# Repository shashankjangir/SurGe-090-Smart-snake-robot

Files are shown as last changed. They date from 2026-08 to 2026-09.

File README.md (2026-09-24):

<p align="center">
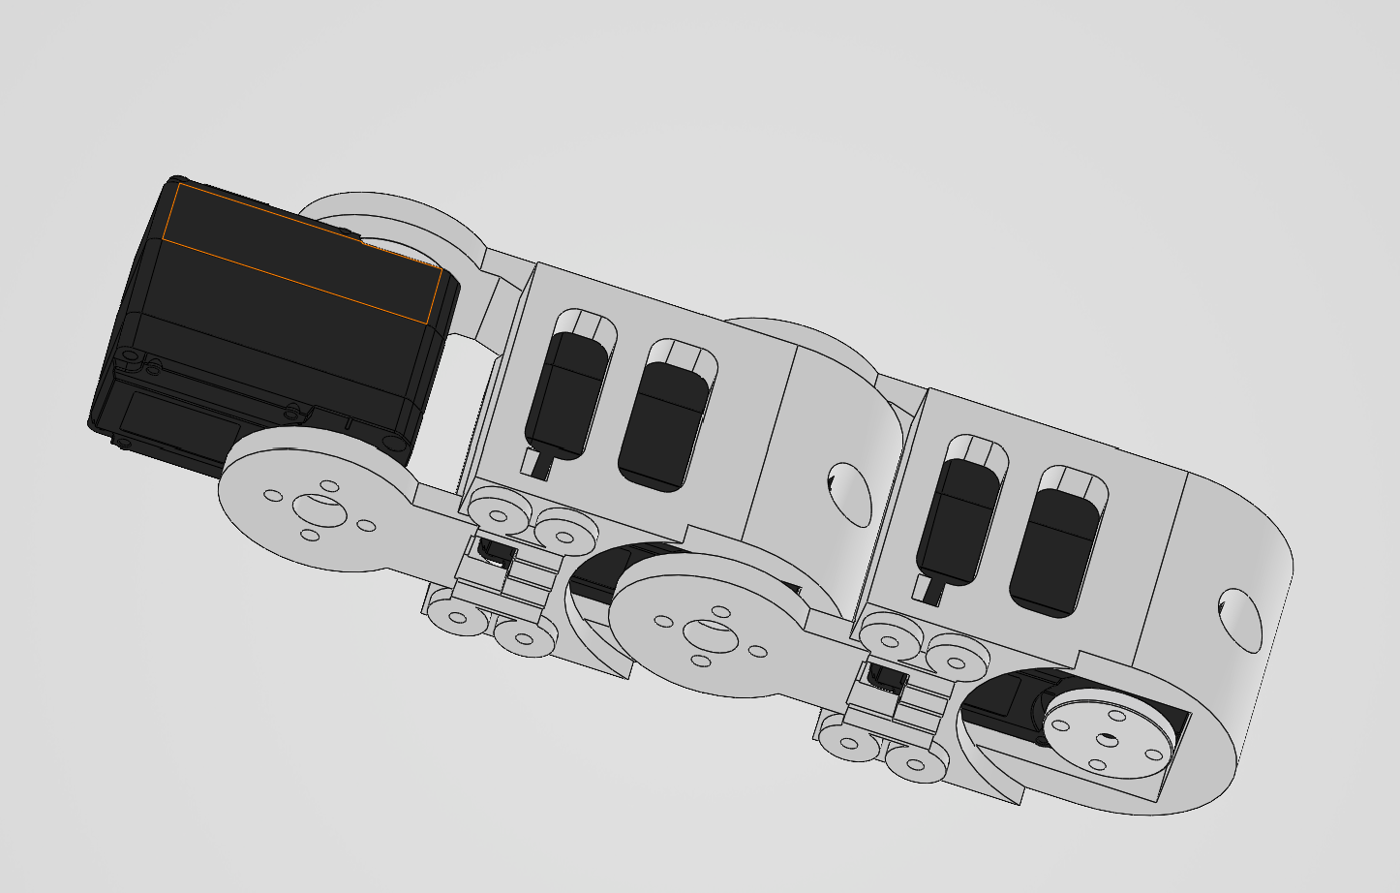
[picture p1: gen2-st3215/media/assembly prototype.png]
SURGE-090 gen2 assembly prototype
  
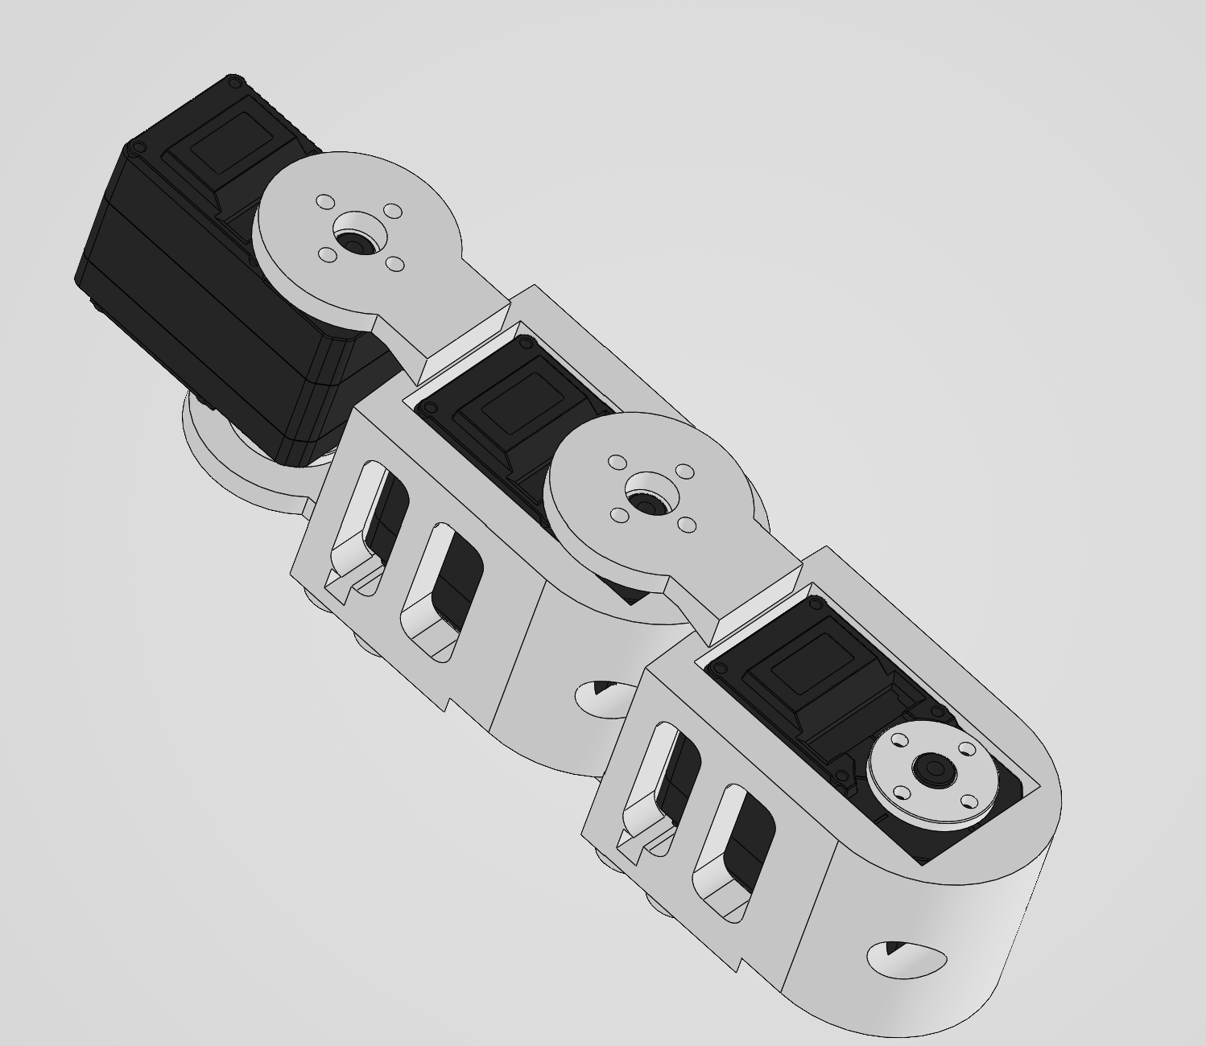
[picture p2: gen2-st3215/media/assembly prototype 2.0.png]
SURGE-090 gen2 assembly prototype 2.0
  
</p>

<h1 align="center">SURGE-090 · Smart Snake Robot 🐍</h1>

<p align="center">
  <b>SURGE Summer Research Programme · Indian Institute of Technology Delhi · 2026</b>
</p>

<p align="center">
  <a href="#abstract">Abstract</a> •
  <a href="#project-status">Status</a> •
  <a href="#the-two-generations">Generations</a> •
  <a href="#system-architecture">Architecture</a> •
  <a href="#repository-structure">Structure</a> •
  <a href="#quick-start">Quick Start</a> •
  <a href="#team">Team</a>
</p>

---

> **Updated 24 Sep 2026.** What we did before and what we do now is recorded in [What changed](#what-changed) at the end of this file.

## Abstract

**SURGE-090** is a ten-degree-of-freedom, bio-inspired snake robot intended for locomotion in unstructured and confined environments. It propels itself by **sinusoidal lateral undulation**, and its central research contribution is **sensorless collision detection**: motor current is monitored continuously, and a stall-current spike is used as a tactile obstacle signal, removing the need for any external proximity or force sensor.

The project was carried out under the **SURGE (Summer Undergraduate Research Grant for Excellence)** programme at **IIT Delhi** in summer 2026, on a ₹1,00,000 grant. It passed through two hardware generations, and the transition between them is the central event in the project's history — see [Why there are two generations](#why-there-are-two-generations).

> **This README is a research log, not a product page.** Every subsystem below is tagged with its real state. Where something is designed but not built, it says so.

---

## Project Status

**Overall: design, simulation, Python bench stack, ESP32 firmware, web dashboard, and desktop app complete; integrated hardware build pending.**

| Subsystem | State | Notes |
|---|---|---|
| Serpenoid gait generator (Python) | 🟢 **Implemented** | Sound math; verified on bench & simulation |
| Current-threshold collision detection | 🟢 **Implemented** | 350 mA (Gen 1) / 1200 mA default (Gen 2); requires bench calibration |
| Evasion state machine | 🟢 **Implemented** | SLITHER → REV (2.5 s) → TURN (4.0 s) → SLITHER |
| Side-aware turn direction | 🟡 **Implemented** | Uses current sign (torque direction); phase-correlation recommended |
| Dynamixel XL330 bus driver (Gen 1) | 🟡 **Written, bench tested** | Verified against **2** motors; 10-motor path written |
| ST3215 servo driver & protocol (Gen 2) | 🟢 **Implemented** | Feetech SCS half-duplex bus @ 1 Mbps with mock support (`gen2-st3215/src/`) |
| ESP32 robot firmware (Gen 2) | 🟢 **Implemented** | Field firmware of record `robot_esp32_v2.cpp`: CPG gait, MPU6050, ESP-NOW, limp boot, per-group soft start, ±70° limits, low-battery/over-temp stop (`robot_esp32` superseded) |
| ESP32 receiver + transmitter | 🟢 **Implemented** | OLED + NeoPixel receiver, ESP-NOW transmitter (`gen2-st3215/firmware/`) |
| ESP-NOW telemetry link (Gen 2) | 🟢 **Implemented** | Broadcast link from robot to base station (`base_esp32.ino` + `base_station.py`) |
| PyBullet physics simulation | 🟢 **Implemented** | 10-segment URDF digital twin with GUI + headless modes (`shared/simulation/pybullet/`) |
| Pure pursuit path following | 🟢 **Implemented** | Kinematic prediction + pure pursuit steering (`gen2-st3215/src/path_engine.py`) |
| Web dashboard (Flask) | 🟢 **Implemented** | REST API, 2D canvas, 3D Three.js viewer, telemetry (`shared/web-dashboard/`) |
| Desktop control app (Tkinter) | 🟢 **Implemented** | GUI + headless mode, path drawing, accuracy reports (`shared/desktop-app/`) |
| ESP32 gait simulation (Wokwi) | 🟢 **Working** | 5 PWM servos, HC-SR04, MPU6050, OLED, interactive serial console |
| Body segment CAD — v1/v2 (SolidWorks) | 🟢 **Printed** | 2 segments printed and measured (Gen 1 Dynamixel) |
| Body segment CAD — v4 (CadQuery) | 🟢 **Complete** | Gen 2 baseline design |
| Body segment CAD — v5 (CadQuery) | 🟡 **Superseded** | Addressed sidewalls; superseded by v6 |
| Body segment CAD — v6 (CadQuery) | 🟢 **Complete (Design of record)** | Fixes ground clearance, scale orientation & retention (`gen2-st3215/cad/segments/v6/`) |
| v2.0 electrical architecture | 🟢 **Specified** | Split power bus v3: 15 A main fuse → loop key → 5 groups of 2 servos, 3 A fuse per group ([`docs/hardware/power_split_bus_v3.md`](docs/hardware/power_split_bus_v3.md)) |
| Assembled 10-DOF physical robot | 🔴 **Pending** | Full 10-motor physical chain assembly pending actuator procurement |

### The hardware blocker

**Only 2 of the 10 planned Dynamixel XL330-M288-T motors were obtained for Gen 1**, after which the part became unavailable in the Indian market. The project was subsequently transitioned to **Waveshare ST3215** serial bus servos, which are readily sourced in India and deliver 2.94 N·m torque (~5.7× the XL330).

### Anisotropic friction requirement

`snake_locomotion.py` generates a planar undulation that produces forward thrust **only if the belly has anisotropic friction** — low resistance sliding forward, high resistance sliding sideways/backward.

The **v6 CAD** addresses this with longitudinal keel features and directional ground contact geometry. Printing and evaluating a single v6 test segment on the target surface is recommended to measure forward/backward traction before full assembly.

---

## Why there are two generations

The redesign was **forced by component supply, not chosen on engineering grounds.** The commit that opens generation 2 records it plainly:

```
a32b675  2026-08-20  "No dynamixel in the market. So switched to Servos"
```

After a six-week stall waiting on motors that were not going to arrive, the architecture was rebuilt around **Waveshare ST3215** serial bus servos, which are readily sourced in India and carry substantially more torque. The move brought genuine secondary benefits — roughly 5.7× the joint torque, and a 12 V rail that supports a larger robot — but those are consequences of the switch, not the reason for it.

---

## The Two Generations

### `gen1-dynamixel/` — original design

| Aspect | Detail |
|---|---|
| **Motors** | 10× ROBOTIS Dynamixel XL330-M288-T (0.52 N·m, 1.5 A stall @ 5 V) — **2 obtained** |
| **Interface** | ROBOTIS U2D2 + Power Hub Board, TTL daisy chain, Protocol 2.0 |
| **Compute** | Raspberry Pi (4 in BOM, 5 used in lab), Python + `dynamixel-sdk` |
| **Power** | 5 V / 10 A SMPS, tethered |
| **Encoder** | 12-bit magnetic absolute, 0.088°/step |
| **Status** | Control stack written; verified on 2-motor bench |
| **Documentation** | [`gen1-dynamixel/README.md`](gen1-dynamixel/README.md) |

### `gen2-st3215/` — ST3215 + ESP32 redesign

| Aspect | Detail |
|---|---|
| **Motors** | 10× Waveshare ST3215 (2.94 N·m / 30 kg·cm, 2.7 A stall @ 12 V) |
| **Interface** | Waveshare Bus Servo Driver (integrated ESP32), Feetech SCS half-duplex TTL @ 1 Mbps |
| **Onboard compute** | ESP32 dev board — **firmware implemented** (`firmware/robot_esp32_v2/`) |
| **Base station** | Raspberry Pi 5 + second ESP32 radio bridge — **implemented** (`base_station.py` + `firmware/base_esp32/`) |
| **Wireless** | ESP-NOW 2.4 GHz peer-to-peer broadcast telemetry |
| **Sensors** | MPU6050 IMU (I²C 0x68), HC-SR04**P** ultrasonic (3.3 V-safe) |
| **Power** | 1× 3S LiPo 1800 mAh → 15 A fuse → XT60 loop key → main line; split bus v3 injects 12 V into 5 groups of 2 servos (3 A fuse each); driver board fed via 7.5 V buck, servo-port +V cut. Mean Well LRS-100-5 for base station 5 V |
| **CAD** | `cad/segments/v6/` parametric CadQuery design of record |
| **Status** | Control stack, mock mode, firmware, and CAD complete |
| **Documentation** | [`gen2-st3215/README.md`](gen2-st3215/README.md) |

> ⚠️ **HC-SR04P only.** A standard HC-SR04 drives its ECHO pin at 5 V and will permanently damage the ESP32 input stage.

### v2.0 power figures (updated)

The original LaTeX report specified 2× 3S 1500 mAh 30C packs in parallel (33.3 Wh total). The actual hardware uses a **single 3S 1800 mAh** pack (20.0 Wh). Since split bus v3 the servos are powered straight from the main line in 5 fused groups, not through the driver board.

| Quantity | Value |
|---|---|
| Pack | 1× 3S LiPo 1800 mAh |
| Voltage | 11.1 V nom / 12.6 V charged / 9.0 V floor |
| Energy | **20.0 Wh** |
| Typical walking load | ~3–5 A total (~0.6–1.0 A per group of 2) |
| Worst-case load (10 servos stalled) | 27 A — per-group 3 A fuses / 15 A main fuse trip first |
| Estimated runtime @ 2 A | **~43 min** (80% DoD) |
| Estimated runtime @ 4 A | **~22 min** |
| Estimated runtime @ 6 A | **~14 min** |

> ⚠️ C-rating and connector type (XT60/XT30/Deans) need to be verified from the pack label. A BMS or LiPo alarm is **not yet acquired** — `robot_esp32_v2` stops at 10.2 V, but a hardware alarm is still recommended.

---

## System Architecture

### v1.0 — Dynamixel (Gen 1)

```
┌────────────────────────────────────────────┐
│              Raspberry Pi                  │
│  main.py ──── control loop @ 50 Hz         │
│     ├──► src/obstacle_avoidance.py         │
│     │        current threshold + FSM       │
│     ├──► src/snake_locomotion.py           │
│     │        travelling sine wave          │
│     └──► dynamixel-sdk                     │
│            write4ByteTxRx  (goal position) │
│            read2ByteTxRx   (present current)│
└──────────────┬─────────────────────────────┘
        │ USB
   ┌────┴─────┐
   │ U2D2+PHB │  5 V power injection
   └────┬─────┘
        │ X3P TTL daisy chain
┌───────▼────────────────────────────────────┐
│  Motor 1 → 2 → … → 10                      │
└────────────────────────────────────────────┘
```

### v2.0 — ST3215 + ESP-NOW (Gen 2)

```
  ┌─── BASE STATION ────────────────────────────┐
  │  Raspberry Pi 5 (base_station.py)           │
  │       ↕ USB Serial @ 115200                 │
  │  ESP32 #2 (firmware/base_esp32)             │
  └──────────────┬──────────────────────────────┘
                 │  ESP-NOW 2.4 GHz Broadcast
  ┌──────────────▼──────────────────────────────┐
  │  ESP32 #1 (firmware/robot_esp32_v2)         │
  │    Onboard: Gait CPG · MPU6050 · Stall FSM  │
  │       ↕ UART (GPIO 18 RX / 19 TX) @ 1 Mbps  │
  │  Waveshare Bus Servo Driver (integrated)    │
  └──────────────┬──────────────────────────────┘
                 │  3-pin half-duplex TTL bus
  ┌──────────────▼──────────────────────────────┐
  │  ST3215 #1 → #2 → … → #10                   │
  └─────────────────────────────────────────────┘
      ⏚ 1× 3S LiPo 1800 mAh → 15 A fuse → XT60 loop key → 12 V main line
        → 5 inject boards (3 A fuse each) → servo groups 1-2 · 3-4 · 5-6 · 7-8 · 9-10
        → 7.5 V buck → driver board (servo-port +V cut: DATA + GND only)
```

---

## Gait Parameters

```python
wave_phase = (wave_dir * self.frequency * current_time) - (i * self.phase_shift)
pos = int(self.center_pos + self.amplitude * math.sin(wave_phase) + bend)
```

| Parameter | Gen 1 (XL330) | Gen 2 (ST3215) | Physical Meaning |
|---|---|---|---|
| `amplitude` | 400 ticks | 400 ticks | **35.2°** peak joint deflection |
| `frequency` | 3.0 rad/s | 3.0 rad/s | **0.477 Hz** gait cycle (period 2.09 s) |
| `phase_shift` | 1.2 rad | 1.2 rad | per joint index |
| `turn_offset` | 300 ticks | 300 ticks | **26.4°** spine bias when turning |
| `center_pos` | 2048 | 2048 | 12-bit encoder neutral |
| `baudrate` | 57600 | 1000000 | Serial communication baud rate |
| `stall_threshold` | 350 mA | 1200 mA | Obstacle trip threshold |

---

## Known Issues & Implementation Notes

1. **Plaintext SSH credentials:** Purged from tracked documentation; ensure any hardware device credentials are rotated.
2. **CAD Evolution:**
   - `segment_v5.py` had a sidewall thickness bug.
   - **`segment_v6.py`** is the **design of record**, fixing ground contact plane, orienting keel scales longitudinally, and providing positive motor retention screws.
3. **ST3215 Control Stack:** Fully ported in `gen2-st3215/src/` with `feetech_protocol.py` (checksum, sync-write, sign-magnitude current decoding) and `servo_driver.py`.
4. **Mock Simulation Mode:** `SURGE_MOCK=1 python main.py` allows full gait and state machine simulation on PC without attached serial hardware.
5. **EEPROM ID Programming:** ST3215 EEPROM unlock (register `55` / `0x37`) is handled in both `gen2-st3215/tools/assign_id.py` and `gen2-st3215/firmware/assign_ids/`.

---

## Repository Structure

```
surge090/
├── README.md                          ← Project overview & research log
├── .gitignore                         # Git exclusion rules
├── .gitattributes                     # Git LFS attributes
│
├── gen1-dynamixel/                    ══ GENERATION 1 (Dynamixel XL330) ══════
│   ├── README.md                      # Gen 1 documentation & user guide
│   ├── main.py                        # Python 50 Hz control loop
│   ├── requirements.txt               # Dependencies (dynamixel-sdk, pyserial)
│   ├── install_requirements.cmd       # Windows dependency installer
│   ├── src/                           # Control modules (Dynamixel SDK)
│   ├── tests/                         # Ping & live feedback test scripts
│   ├── cad/                           # SolidWorks CAD models & assemblies
│   │   ├── segments/                  # Segment 1 & 2 parts/STLs
│   │   ├── assembly/                  # 10-joint assembly
│   │   └── motor-ref/                 # XL330 CAD reference models
│   ├── hardware/                      # BOM.xlsx, Dynamixel_Selection.md
│   ├── docs/                          # Guides, safety, wiring & presentations
│   └── media/                         # Hardware photos, renders & test footage
│
├── gen2-st3215/                       ══ GENERATION 2 (Waveshare ST3215) ═════
│   ├── README.md                      # Gen 2 documentation & quick start
│   ├── PORTING_STATUS.md              # Porting matrix & register map
│   ├── main.py                        # Bench gait loop (supports SURGE_MOCK=1)
│   ├── base_station.py                # Pi 5 ESP-NOW telemetry logger
│   ├── servo_test.py                  # Single-motor position sweep
│   ├── requirements.txt               # Dependencies (pyserial)
│   ├── src/                           # ST3215 control stack
│   │   ├── feetech_protocol.py        # Feetech SCS packet layer & checksums
│   │   ├── servo_driver.py            # ST3215 HAL with Mock & SyncWrite
│   │   ├── robot_config.py            # Hardware config & St3215Addr
│   │   ├── snake_locomotion.py        # Serpenoid gait engine (all-yaw)
│   │   ├── obstacle_avoidance.py      # Current-threshold FSM
│   │   ├── st3215_interface.py        # Serial bridge to ESP32 (P/T/I protocol)  ★
│   │   ├── path_engine.py             # Pure pursuit path following engine       ★
│   │   ├── utils.py                   # Current conversion & angle math
│   │   ├── kinematics.py              # Curvature wave model
│   │   └── torque_controller.py       # PD compliance model
│   ├── tests/                         # ST3215 ping & telemetry tests
│   ├── tools/                         # EEPROM unlock, ID programming & CLI tester
│   ├── firmware/                      # Arduino / ESP32 firmware
│   │   ├── README.md                  # Firmware guide & flash instructions
│   │   ├── robot_esp32_v2/            # Field master of record (split bus v3, safe start)
│   │   ├── robot_esp32/               # Superseded field master (reference only)
│   │   ├── spin_all/                  # Broadcast sweep smoke test
│   │   ├── base_esp32/                # ESP-NOW to USB serial receiver
│   │   ├── usb_servo_bridge/          # 1 Mbps transparent USB-UART bridge
│   │   ├── assign_ids/                # Interactive ID assignment sketch
│   │   ├── esp32_st3215_receiver/     # OLED+NeoPixel receiver (USB+ESP-NOW)     ★
│   │   └── esp_now_transmitter/       # Wireless command relay transmitter       ★
│   ├── cad/                           # Parametric CadQuery segment models
│   │   ├── motor-ref/                 # ST3215 STEP, DXF & drawing
│   │   └── segments/
│   │       ├── v4/                    # Baseline CadQuery segment
│   │       ├── v5/                    # Intermediate iteration
│   │       └── v6/                    # Design of record (segment_v6.py)
│   ├── docs/                          # Wiring diagrams, SVG & parts lists
│   └── progress/                      # Electrical system LaTeX reports
│
├── shared/                            ══ SHARED APPS & TOOLS ══════════════════
│   ├── web-dashboard/                 # WEB CONTROL DASHBOARD (Flask)           ★
│   │   ├── README.md                  
│   │   ├── web_app.py                 
│   │   ├── requirements.txt           
│   │   ├── templates/                 
│   │   └── static/                    
│   │
│   ├── desktop-app/                   # DESKTOP CONTROL APP (Tkinter)           ★
│   │   ├── README.md                  
│   │   └── app.py                     
│   │
│   └── simulation/                    # SIMULATIONS 
│       ├── wokwi/                     # Wokwi ESP32 browser simulation
│       │   └── sketch.ino             
│       └── pybullet/                  # PyBullet physics digital twin           ★
│           └── simulation_interface.py
│
├── docs/                              ══ PROJECT DOCUMENTATION ════════════════ ★
│   ├── 1_APP_USAGE_MANUAL.md          # App usage guide (headless + GUI + remote)
│   ├── 3_RASPBERRY_PI_SETUP.md        # 8-phase Pi setup (OS→SSH→X11→Ollama)
│   ├── 4_LLM_AUTONOMY_SETUP.md        # LLM brain architecture for Pi 5
│   ├── 4_WIRING_DIAGRAM.md            # Gen 2 wiring (split bus v3)
│   ├── 5_PARTS_AND_SAFETY.md          # Parts and safety guidelines
│   ├── 6_ADDITIONAL_PARTS.md          # Additional parts documentation
│   ├── 7_TELEMETRY_AND_PERFORMANCE.md # Telemetry and performance documentation
│   ├── API_DOCUMENTATION.md           # Serial protocol API (Python + C++ templates)
│   ├── hardware/                      # Power & wiring design
│   │   ├── README.md                  # Index + design history (before → now)
│   │   ├── Updated_Hardware_Inventory.md # BOM, specs & cost analysis
│   │   ├── power_split_bus_v3.md      # Current power design (5 groups × 2 servos)
│   │   ├── wiring_split_bus_v3.svg    # Current wiring diagram
│   │   ├── wiring_split_bus_v2.svg    # Superseded (4+3+3)
│   │   ├── wiring_centre_fed_v1.svg   # Superseded (centre-fed)
│   │   ├── power_split_bus_v2.md / power_centre_fed_v1.md   # Superseded designs
│   │   └── wiring_diagram_v1.svg / system_architecture.svg  # Superseded first Gen 2 concept
│   ├── Component_flow.png             # System component flow diagram
│   └── smart-snake-calculations.pdf   # Engineering calculations document
│
└── platformio.ini                     # PlatformIO build config
```

> ★ = Newly integrated from the `Snake_SURGE` standalone prototype

---

## Quick Start

### 1. Web Dashboard (Easiest — no hardware required)

Launch the Flask web dashboard with PyBullet simulation:
```bash
cd shared/web-dashboard
pip install -r requirements.txt
python web_app.py
```
Open **http://localhost:5000** in your browser. Select "Simulation (PyBullet)", click Connect, and draw a path!

### 2. Desktop App (Tkinter GUI + PyBullet)

```bash
cd shared/desktop-app
python app.py --gui
```
Select "Simulation (PyBullet)" and click "Connect Engine" to launch the 3D physics window.

### 3. Wokwi Simulation (Browser-only, no install)

Run the 5-servo snake robot in your browser:  
🔗 **[wokwi.com/projects/467623718124707841](https://wokwi.com/projects/467623718124707841)**

Includes real-time serpenoid gait generation, HC-SR04 obstacle detection with hysteresis, MPU6050 orientation tracking, SSD1306 OLED display, and a live serial tuning console at 115200 baud (`f`, `b`, `l`, `r`, `s`, `a`, `A<deg>`, `S<speed>`, `?`).

### 4. Gen 2 — ST3215 (Python Bench & Mock)

```bash
cd "gen2-st3215"
pip install -r requirements.txt
```

**Run in Mock mode (no hardware connected):**
```bash
# Windows
set SURGE_MOCK=1
python main.py

# Linux / macOS
SURGE_MOCK=1 python main.py
```

**Run with Hardware Bench:**
1. Flash `firmware/usb_servo_bridge` onto the ESP32 Servo Driver.
2. Connect ST3215 servos with IDs 1–10.
3. Run verification and control loop:
```bash
python tests/test_st3215_ping.py
python tests/test_motor_feedback.py
python main.py
```

### 5. Gen 2 — ST3215 (Field Mode / Untethered)

1. Flash `robot_esp32_v2` onto the robot's onboard ESP32 (`pio run -e robot_esp32_v2 -t upload` from the repo root). It boots limp — type `RUN` in the serial monitor or send it from the base station.
2. Flash `firmware/base_esp32` onto the base station ESP32 connected to Raspberry Pi 5.
3. On the Raspberry Pi:
```bash
python base_station.py --port /dev/ttyUSB0
```

### 6. Gen 1 — Dynamixel XL330

```bash
cd "gen1-dynamixel"
pip install -r requirements.txt
python tests/test_dynamixel_ping.py
python main.py
```

---

## Documentation

| Document | Path | Description |
|---|---|---|
| **Web Dashboard Guide** | [`shared/web-dashboard/README.md`](shared/web-dashboard/README.md) | Flask web dashboard & REST API reference |
| **Desktop App Guide** | [`shared/desktop-app/README.md`](shared/desktop-app/README.md) | Tkinter desktop control suite |
| **PyBullet Simulation Guide** | [`shared/simulation/pybullet/README.md`](shared/simulation/pybullet/README.md) | Physics digital twin documentation |
| **App Usage Manual** | [`docs/1_APP_USAGE_MANUAL.md`](docs/1_APP_USAGE_MANUAL.md) | Headless, GUI, and remote access modes |
| **Raspberry Pi Setup** | [`docs/3_RASPBERRY_PI_SETUP.md`](docs/3_RASPBERRY_PI_SETUP.md) | 8-phase Pi setup (OS → SSH → X11 → Ollama) |
| **LLM Autonomy Setup** | [`docs/4_LLM_AUTONOMY_SETUP.md`](docs/4_LLM_AUTONOMY_SETUP.md) | Local LLM brain architecture for Pi 5 |
| **Serial API Documentation** | [`docs/API_DOCUMENTATION.md`](docs/API_DOCUMENTATION.md) | Protocol templates (Python + C++) |
| **Gen 2 ST3215 Overview** | [`gen2-st3215/README.md`](gen2-st3215/README.md) | Generation 2 system guide |
| **Gen 2 Porting Status** | [`gen2-st3215/PORTING_STATUS.md`](gen2-st3215/PORTING_STATUS.md) | ST3215 porting details & register map |
| **Gen 2 Firmware Guide** | [`gen2-st3215/firmware/README.md`](gen2-st3215/firmware/README.md) | ESP32 flashing instructions |
| **CAD Segment v6 Guide** | [`gen2-st3215/cad/segments/v6/README.md`](gen2-st3215/cad/segments/v6/README.md) | v6 design of record documentation |
| **Hardware Inventory & BOM** | [`docs/hardware/Updated_Hardware_Inventory.md`](docs/hardware/Updated_Hardware_Inventory.md) | Parts, specifications & budget analysis |
| **Gen 1 Dynamixel Overview** | [`gen1-dynamixel/README.md`](gen1-dynamixel/README.md) | Generation 1 system guide |
| **Motor Trade Study** | [`gen1-dynamixel/hardware/Dynamixel_Selection.md`](gen1-dynamixel/hardware/Dynamixel_Selection.md) | XL330 vs AX-12A vs SG90 comparison |
| **Hardware design index & history** | [`docs/hardware/README.md`](docs/hardware/README.md) | Current vs superseded power designs, and why each changed |
| **Power design — split bus v3** | [`docs/hardware/power_split_bus_v3.md`](docs/hardware/power_split_bus_v3.md) | Current power architecture, parts & build order |
| **Wiring diagram — split bus v3 (SVG)** | [`docs/hardware/wiring_split_bus_v3.svg`](docs/hardware/wiring_split_bus_v3.svg) | Current wiring diagram |
| **v2.0 Wiring Diagram (SVG, older)** | [`gen2-st3215/docs/snake_robot_wiring_diagram.svg`](gen2-st3215/docs/snake_robot_wiring_diagram.svg) | Electrical schematic & pinouts |
| **v2.0 Electrical Report** | [`gen2-st3215/progress/electrical_system_report.pdf`](gen2-st3215/progress/electrical_system_report.pdf) | Safety architecture & power analysis |
| **Wokwi Simulation Guide** | [`shared/simulation/wokwi/README.md`](shared/simulation/wokwi/README.md) | ESP32 browser simulation notes |
| **Wiring Diagram (Gen 2)** | [`docs/4_WIRING_DIAGRAM.md`](docs/4_WIRING_DIAGRAM.md) | Split bus v3 connection tables, pinout & build order |
| **Parts & Safety** | [`docs/5_PARTS_AND_SAFETY.md`](docs/5_PARTS_AND_SAFETY.md) | Parts and safety guidelines |
| **Telemetry & Performance** | [`docs/7_TELEMETRY_AND_PERFORMANCE.md`](docs/7_TELEMETRY_AND_PERFORMANCE.md) | Telemetry and performance documentation |

---

## Team

**SURGE-090 — Smart Snake Robot** · IIT Delhi · Summer 2026  
Supervisor: **Prof. Amartansh Dubey**

| Member | Entry No. | Role |
|---|---|---|
| Shashank Jangir | 2024EE11048 | Project lead · hardware · CAD · Electronics |
| Bhavesh Bansiwal | 2024ME10487 | Software · mechanical · CAD |
| Mahima Chotiya | 2024ME11187 | Mathematics · physics |

---

## Acknowledgements

Carried out under the **SURGE (Summer Undergraduate Research Grant for Excellence)** programme at **IIT Delhi**. We thank our supervisor and the Department of Mechanical Engineering for their guidance and laboratory resources.

---

## License

© 2026 SURGE-090 Team, IIT Delhi. All rights reserved.  
Shared for academic and research purposes only.

---

## What changed

### 24 Sep 2026

| Topic | Before | Now | Why |
|---|---|---|---|
| Power design | 3S LiPo → fuse (size TBD) → loop key (TBD) → 12 V direct to driver VIN → servos | Split bus v3: 15 A fuse → XT60 loop key → main line → 5 groups of 2 servos, 3 A fuse each; 7.5 V buck powers the driver | Each plug carries only 2 servos' current, a jam takes out only 2 joints, and the voltage drop is almost zero (see `power_split_bus_v3.md`) |
| Power design history | — | Centre-fed v1 → split bus v2 (4+3+3) → split bus v3 (2+2+2+2+2) | Each step put fewer servos on one plug and fuse |
| Field firmware | `robot_esp32.ino` | `robot_esp32_v2.cpp` (old one superseded) | With 3 A fuses per pair of servos, starting all 10 servos at once could blow fuses; v2 also adds battery/temperature protection; sketches are `.cpp` so PlatformIO builds them |
| Hardware inventory | `Updated_Hardware_Inventory.md` at repo root | `docs/hardware/Updated_Hardware_Inventory.md` | File was moved; old link was broken |
| Wiring doc | `docs/4_WIRING_DIAGRAM.md` held the Gen 1 wiring | It holds the Gen 2 split bus v3 wiring; Gen 1 copy stays in `gen1-dynamixel/docs/` | Doc matches the robot being built |
| Superseded designs | Only in the claude.ai project | Copied into `docs/hardware/` with an index showing the history | Keep the reasons for each change with the repo |

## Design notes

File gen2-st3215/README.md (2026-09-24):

# SURGE-090 · Generation 2 (Waveshare ST3215)

Python bench stack and ESP32 firmware for the **ST3215** snake. This is **not** a Dynamixel / XL330 tree. Generation 1 lives in [`../gen1-dynamixel/`](../gen1-dynamixel/). Project-wide context: [`../README.md`](../README.md). Porting notes: [`PORTING_STATUS.md`](PORTING_STATUS.md).

**Motors:** Waveshare / Feetech ST3215 (SMS/STS, 12-bit encoder, ~2.94 N·m @ 12 V).  
**Bus:** Feetech Protocol 1-style, **1 Mbps**, daisy-chained 3-pin TTL.  
**Power:** 3S LiPo into driver **VIN (6.0–12.6 V)**. Never 5 V Mean Well on the servo rail.

---

## Two ways to run

| Mode | Master | When |
|---|---|---|
| **Bench** | PC / Pi Python (`main.py`) | USB CDC through the Waveshare ESP32 flashed as a **transparent 1 Mbps bridge** |
| **Field** | Robot ESP32 (`firmware/robot_esp32`) | Onboard gait, current stall FSM, MPU6050, ESP-NOW telemetry |

The two modes are mutually exclusive on the same board: flash **either** `usb_servo_bridge` **or** `robot_esp32`.

```
Bench
  PC (main.py @ 50 Hz)  --USB CDC 1 Mbps-->  ESP32 bridge  --UART GPIO18/19-->  ST3215 #1…#10

Field
  Pi 5 (base_station.py)  --USB 115200-->  ESP32 #2 (base_esp32)
        ^ ESP-NOW telemetry (broadcast)
  Robot ESP32 (gait + IMU)  --UART GPIO18/19 1 Mbps-->  ST3215 #1…#10
        VIN: 3S LiPo 6.0–12.6 V
```

Servo UART on the Waveshare Servo Driver with ESP32 defaults to **GPIO 18 RX / 19 TX**. If ping is silent, swap those pins.

---

## Features

| Feature | Detail |
|---|---|
| **10-DOF planar gait** | All joints yaw (shaft along Z). Travelling sine wave; parameters in `src/robot_config.py` |
| **Current stall detection** | `PRESENT_CURRENT` (addr 69), sign-magnitude, 6.5 mA/count. Trip starts at **1200 mA** — calibrate on hardware |
| **Evasion FSM** | SLITHER → reverse 2.5 s → turn 4.0 s → resume. Detection is off during the 6.5 s manoeuvre |
| **Pure pursuit path following** | `src/path_engine.py` — kinematic forward prediction + pure pursuit steering for waypoint tracking |
| **ESP32 receiver firmware** | `firmware/esp32_st3215_receiver/` — OLED + NeoPixel status, USB + ESP-NOW dual input, ST3215 SCServo bridge |
| **ESP-NOW wireless transmitter** | `firmware/esp_now_transmitter/` — relays serial commands wirelessly to the receiver ESP32 |
| **Serial bridge interface** | `src/st3215_interface.py` — PySerial bridge to ESP32 with P/T/I command protocol |
| **Interactive terminal tester** | `tools/test_st3215_terminal.py` — CLI for position control, centering, telemetry, and ID assignment |
| **Mock bus** | `SURGE_MOCK=1 python main.py` runs the loop with no serial |
| **ID programming** | One servo at a time: Arduino `firmware/assign_ids` or `python tools/assign_id.py` |

---

## Repository layout

```
gen2-st3215/
├── main.py                      # Bench gait loop (needs usb_servo_bridge)
├── base_station.py              # Pi: print ESP-NOW telemetry from base_esp32
├── servo_test.py                # Single-ID position sweep
├── requirements.txt             # pyserial only (no dynamixel-sdk)
├── PORTING_STATUS.md
├── src/
│   ├── robot_config.py          # Config + St3215Addr control table
│   ├── feetech_protocol.py      # Packet layer (FF FF … checksum)
│   ├── servo_driver.py          # HAL: ping, torque, sync goal, current
│   ├── snake_locomotion.py      # Active gait (all-yaw when PLANAR_ALL_YAW)
│   ├── obstacle_avoidance.py    # Current FSM
│   ├── st3215_interface.py      # Serial bridge to ESP32 (P/T/I protocol)   ★ NEW
│   ├── path_engine.py           # Pure pursuit path following engine         ★ NEW
│   ├── utils.py                 # Sign-magnitude current, encoder ↔ rad
│   ├── kinematics.py            # Bellows model — not used by main.py
│   └── torque_controller.py     # PD torque — unused; bus is position mode
├── tests/
│   ├── test_st3215_ping.py
│   └── test_motor_feedback.py
├── tools/
│   ├── assign_id.py             # EEPROM unlock + ID write
│   └── test_st3215_terminal.py  # Interactive CLI servo tester              ★ NEW
├── firmware/                    # Arduino: ESP32 Dev Module
│   ├── assign_ids/
│   ├── usb_servo_bridge/
│   ├── robot_esp32/
│   ├── base_esp32/
│   ├── esp32_st3215_receiver/   # OLED+NeoPixel receiver (USB+ESP-NOW)      ★ NEW
│   └── esp_now_transmitter/     # Wireless command relay transmitter        ★ NEW
└── cad/
    ├── assembly/                # SolidWorks snake assembly
    └── segments/v6/             # Design of record (CadQuery)
```

---

## Hardware assumptions

| Item | Value |
|---|---|
| Joints | 10, IDs 1–10 |
| Encoder | 0–4095, centre **2048** |
| Baud | **1 000 000** |
| Stall / free-run (datasheet) | ~2700 mA / ~200 mA |
| Obstacle trip (code default) | **1200 mA** — starting guess, not a bench measurement |
| IMU (field only) | MPU6050, I²C 0x68, SDA **21** / SCL **22**; gait continues if IMU is missing |
| Camera | Raspberry Pi Camera Module 3 on Pi CSI — not on the ESP32 |

XL6009 boost is **not** in the servo path (it would over-voltage a 3S pack).

---

## Software setup (bench)

Python 3.8+, Waveshare driver with **`firmware/usb_servo_bridge`** flashed.

```cmd
install_requirements.cmd
```

```bash
pip install -r requirements.txt
```

Serial port: set `SURGE_PORT` or edit the default in `default_serial_port()` (`COM3` on Windows, `/dev/ttyUSB0` or `/dev/ttyACM0` on Linux).

### Assign IDs (one servo on the bus)

Factory ID is usually `1`. EEPROM must be unlocked (register 55) before the ID write — `tools/assign_id.py` does that.

```bash
python tools/assign_id.py --new 3
python tools/assign_id.py --old 1 --new 7
```

Alternatively flash `firmware/assign_ids`. Daisy-chain only after IDs 1–10 are unique.

### Verify and run

```bash
python tests/test_st3215_ping.py
python tests/test_motor_feedback.py
python servo_test.py
python main.py
```

Mock (no hardware):

```bash
set SURGE_MOCK=1
python main.py
```

Ctrl+C disables torque in the `finally` block.

### Field

1. Flash `firmware/robot_esp32` on the Waveshare driver (gait master).
2. Flash `firmware/base_esp32` on a second ESP32 plugged into the Pi.
3. On the Pi: `python base_station.py --port /dev/ttyUSB0`

Serial monitor on the robot board (115200) prints MAC and telemetry. Type `RUN` / `STOP` on robot or base. Telemetry is ESP-NOW **broadcast** so the base does not need a hardcoded robot MAC.

Details: [`firmware/README.md`](firmware/README.md).

### ESP32 Receiver + Transmitter (from Snake_SURGE)

The `esp32_st3215_receiver` firmware is a standalone receiver that:
- Accepts commands over **USB Serial** and **ESP-NOW** simultaneously
- Drives ST3215 servos via `SCServo.h` library
- Shows connection status on **SSD1306 OLED** (MAC address, USB/Wireless/Both)
- **NeoPixel LED** indicators: breathing white (idle), blue (USB), green (wireless), red (overload)
- Supports `P` (position), `T` (telemetry), `I` (ID assign) commands

The `esp_now_transmitter` relays commands from any USB host to the receiver wirelessly. Plug it into a laptop or Pi, send serial commands, and they are forwarded over ESP-NOW.

### Interactive Terminal Tester

```bash
python tools/test_st3215_terminal.py --port COM10
```

Commands: `p <id> <pos>` (move), `c` (center), `t` (telemetry), `i <new_id>` (assign ID), `q` (quit).

---

## Control table (implemented)

| Item | Address | Size | Notes |
|---|---|---|---|
| ID | 5 | 1 | EEPROM |
| TORQUE_ENABLE | 40 | 1 | 0 off, 1 on |
| ACC | 41 | 1 | `Config.GOAL_ACC` |
| GOAL_POSITION | 42 | 2 | Little-endian ticks; sync-write also packs time + speed |
| PRESENT_POSITION | 56 | 2 | |
| PRESENT_CURRENT | 69 | 2 | Bit 15 = sign, LSB = 6.5 mA |

Packet: `FF FF | ID | LEN | INST | PARAMS | CHECKSUM` with `checksum = ~(ID+LEN+INST+PARAMS) & 0xFF`.

---

## Gait (`Config`)

| Parameter | Value | Meaning |
|---|---|---|
| `GAIT_AMPLITUDE` | 400 ticks | ~35° peak |
| `GAIT_FREQUENCY` | 3.0 rad/s | ~0.48 Hz cycle |
| `GAIT_PHASE_SHIFT` | 1.2 rad | per joint index |
| `GAIT_TURN_OFFSET` | 300 ticks | uniform yaw bias while turning |
| `GOAL_SPEED` / `GOAL_ACC` | 2400 / 50 | limits first-move slam |
| `PLANAR_ALL_YAW` | `True` | every joint is driven (no gen1 pitch-hold) |

Evasion:

```
SLITHER ──(|I| > 1200 mA)──► SLITHER_REV (2.5 s) ──► SLITHER_TURN (4.0 s) ──► SLITHER
```

Turn direction still uses the **sign of present current**, which is torque direction, not obstacle side. Treat side-awareness as a known limitation until joint-index / phase comparison is added.

`kinematics.py` and `torque_controller.py` are present for experiments; **live control is position-mode `SnakeKinematics`**.

### Path Engine (`src/path_engine.py`)

Pure pursuit path following with predictive forward kinematics:
- `predict_path()` — projects the snake's future kinematic path
- `calculate_pure_pursuit()` — calculates steering curvature to reach the next lookahead waypoint
- Used by the [Web Dashboard](../shared/web-dashboard/) and [Desktop App](../shared/desktop-app/) for autonomous path tracking

### ST3215 Interface (`src/st3215_interface.py`)

Serial bridge interface for controlling ST3215 servos via an ESP32 bridge board:
- `connect()` / `disconnect()` — serial port management
- `write_positions({id: pos, ...})` — sends `P,id:pos,...\n` commands
- `read_telemetry()` — sends `T\n` and parses `T,id:load:vel:pos,...` response

---

## CAD

Print from **`cad/segments/v6/`** (CadQuery). v5 had a dimensional error; v4/v5 also had ground-contact and scale-orientation issues that v6 addresses. Motor STEP: `cad/motor-ref/ST3215.step`. Probe before print: `cad/segments/v6/probe_st3215.py`.

---

## Safety

- Servo VIN: **6.0–12.6 V only**. 5 V will brown out or fail to run ST3215s; >12.6 V risks the bus.
- Program IDs with **one** servo connected.
- Keep horns clear during `servo_test.py` and first `main.py` runs.
- Calibrate `OBSTACLE_CURRENT_THRESHOLD_MA` against measured free-run vs stall before relying on evasion.

---

## Team

**SURGE-090 — Smart Snake Robot** · IIT Delhi · SURGE 2026

| Member | Role |
|---|---|
| Shashank Jangir | Project Lead / Software / Electronics & Wiring |
| Bhavesh | Hardware & Mechanical/ Software |
| Mahima | Mechanical / Mathematics |

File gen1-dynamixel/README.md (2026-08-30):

# SURGE-090 · Generation 1 (Dynamixel XL330)

**SURGE Summer Research Programme · Indian Institute of Technology Delhi**

> ⚠️ **HISTORICAL — This generation's hardware is no longer held.**
> The Dynamixel XL330 motors were unobtainable in India at the required quantity (10 units).
> All Gen 1 hardware (U2D2, PHB, Pi 4, cables) has been returned. This directory is preserved
> as a reference for the control architecture, which was ported to Gen 2.
>
> **Active generation:** [`gen2-st3215/`](../gen2-st3215/) · **Current inventory:** [`Updated_Hardware_Inventory.md`](../Updated_Hardware_Inventory.md)

---

## Abstract

SURGE-090 is a ten-degree-of-freedom, bio-inspired snake robot designed for locomotion in unstructured and confined environments. The platform employs sinusoidal lateral undulation to propel itself forward and uses proprioceptive motor-current sensing as a tactile collision detector — eliminating the need for any external proximity or force sensors. The control architecture is implemented in Python running on a Raspberry Pi, communicating with ROBOTIS Dynamixel XL330 smart servo actuators over a TTL serial daisy chain.

The project was developed as part of the **SURGE (Summer Undergraduate Research Grant for Excellence)** programme at **IIT Delhi**.

---

## Table of Contents

1. [Features](#features)
2. [System Architecture](#system-architecture)
3. [Repository Structure](#repository-structure)
4. [Hardware Requirements](#hardware-requirements)
5. [Software Setup](#software-setup)
6. [Running the Robot](#running-the-robot)
7. [Module Reference](#module-reference)
8. [CAD Files](#cad-files)
9. [Documentation](#documentation)
10. [Team](#team)

---

## Features

| Feature | Description |
|---|---|
| **10-DOF Serpentine Gait** | Sinusoidal lateral undulation via a travelling sine wave propagated across all joints |
| **Sensorless Obstacle Detection** | Motor current monitored at 50 Hz; stall current spike (> 350 mA) triggers evasion |
| **Autonomous Evasion** | State machine: reverse (2.5 s) → side-aware turn (4 s) → resume forward |
| **Side-Aware Turning** | Sign of the stalling motor's current determines which way the robot evades |
| **Tethered & Untethered Modes** | Works via USB from a laptop or fully autonomous on on-board Raspberry Pi |
| **3D-Printed Body** | All structural segments designed in SolidWorks; STEP and STL files provided |

---

## System Architecture

```
┌────────────────────────────────────────────┐
│              Raspberry Pi 5                │
│                                            │
│  main.py  ──── Control Loop @ 50 Hz        │
│     │                                      │
│     ├──► src/obstacle_avoidance.py         │
│     │        Current-based state machine   │
│     │        SLITHER → REV → TURN → ...    │
│     │                                      │
│     ├──► src/snake_locomotion.py           │
│     │        Sinusoidal gait generator     │
│     │        turn_direction from avoidance │
│     │                                      │
│     └──► Dynamixel SDK                     │
│               write4ByteTxRx (positions)   │
│               read2ByteTxRx  (current)     │
└──────────────┬─────────────────────────────┘
        │ USB  ←→  ROBOTIS U2D2
        ┌──────┴──────┐
        │  U2D2 + PHB  │  (power injection at 5V)
        └──────┬───────┘
        │ X3P TTL cables — daisy chain
┌───────────▼──────────────────────────────┐
│  Motor 1 → Motor 2 → … → Motor 10        │
│       ROBOTIS Dynamixel XL330-M288-T      │
└───────────────────────────────────────────┘
```

**Obstacle Evasion State Machine**

```
SLITHER ──(|I| > 350 mA)──► SLITHER_REV (2.5 s)
                                │
                        (timer expires)
                                ▼
                        SLITHER_TURN (4.0 s)
                                │
                        (timer expires)
                                ▼
                        SLITHER
```

---

## Repository Structure

```
gen1-dynamixel/
├── main.py                          # Entry point — 50 Hz control loop
├── requirements.txt                 # Python dependencies (dynamixel-sdk, pyserial)
├── install_requirements.cmd         # Windows one-click installer
│
├── src/                             # Core robot software
│   ├── __init__.py
│   ├── robot_config.py              # All hardware constants & tuning parameters
│   ├── utils.py                     # Shared utilities (current sign conversion)
│   ├── snake_locomotion.py          # Sinusoidal gait engine
│   ├── obstacle_avoidance.py        # Collision state machine
│   ├── kinematics.py                # Bellows-model joint angle calculator
│   ├── servo_driver.py              # HAL — mock + Dynamixel SDK interface
│   └── torque_controller.py         # PD torque controller with compliance
│
├── tests/                           # Hardware validation scripts
│   ├── test_dynamixel_ping.py       # Ping all motors; report missing IDs
│   └── test_motor_feedback.py       # Live position / velocity / current readout
│
├── hardware/                        # Procurement & Motor selection
│   ├── BOM.xlsx
│   └── Dynamixel_Selection.md
│
├── docs/                            # All project documentation
│   ├── reports/
│   │   ├── hardware_bom.md          # Bill of Materials (budget: ₹1,00,000)
│   │   ├── starter_kit_manual.md    # First-time single-motor setup guide
│   │   └── README_v1.md             # Archived v1 README
│   ├── datasheets/
│   │   ├── XL,XC-330.pdf            # ROBOTIS XL330 / XC330 datasheet
│   │   ├── DYNAMIXEL_XL330_1__52682.png
│   │   └── Raspberry-Pi-5-Pinout-.jpg
│   ├── presentations/
│   │   └── Smart_Snake_Robot_SURGE090_Progress_Review - Repaired.pptx
│   ├── Component_flow.png           # System component flow diagram
│   ├── SSH_LOGIN_INSTRUCTIONS.md
│   ├── wiring_diagram.md
│   ├── raspberry_pi_setup_guide.md
│   └── parts_and_safety.md
│
├── cad/                             # SolidWorks / STEP / STL design files
│   ├── segments/
│   │   ├── segment1.SLDPRT / .step / _v1.stl
│   │   ├── segment1_alt.SLDPRT
│   │   └── segment2.SLDPRT / .step / _v1.stl
│   ├── assembly/
│   │   └── assembly.SLDASM
│   └── motor-ref/
│       ├── XL,XC-330.stp           # Dynamixel motor reference model
│       └── XL,XC-330.SLDASM
│
└── media/                           # Hardware photos, CAD renders & demo videos
    ├── hardware/                    # Motor & electronics product photos
    ├── cad/                         # CAD render screenshots
    └── testing/                     # Hardware test photos & demo video
```

---

## Hardware Requirements (Historical)

> ⚠️ **None of this hardware is still held.** All items were returned after the project pivoted to Gen 2 (ST3215). This table is preserved as a historical record. See [`docs/reports/hardware_bom.md`](docs/reports/hardware_bom.md) for the full carry-forward analysis.

| Component | Qty Planned | Obtained | Status | Notes |
|---|:---:|:---:|---|---|
| Dynamixel XL330-M288-T | 10 + 2 spares | **2** | Returned | Core joints; 0.52 Nm @ 5V |
| ROBOTIS U2D2 (USB-TTL) | 1 | 1 | Returned | Serial bridge to motors |
| U2D2 Power Hub Board (PHB) | 1 | 1 | Returned | 5V power injection into bus |
| Raspberry Pi 4 (4 GB) | 1 | 1 | Returned | On-board compute |
| Mean Well LRS-100-5 SMPS | 1 | 1 | **Carried to Gen 2** | Now base station / bench supply |
| Dynamixel X3P Cables (×10) | 1 pack | 1 | Returned | Daisy-chain data + power |

**Actual spend:** ~₹22,400 of ₹1,00,000 budget. Remaining ~₹77,600 was applied to Gen 2 procurement.

> Full specifications: [`docs/reports/hardware_bom.md`](docs/reports/hardware_bom.md)

---

## Software Setup

### Prerequisites

- Python 3.8+
- ROBOTIS U2D2 connected via USB

### 1. Install Dependencies

**Windows (one-click):**
```cmd
install_requirements.cmd
```

**Any platform:**
```bash
pip install -r requirements.txt
```

> Dependencies: `dynamixel-sdk >= 4.0.5`, `pyserial >= 3.5`

### 2. Set COM Port

Open [`main.py`](main.py) and confirm the serial port for your system:

```python
# Windows
DEVICENAME = 'COM3'

# Linux / Raspberry Pi
DEVICENAME = '/dev/ttyUSB0'
```

Find the correct port in **Device Manager** (Windows) or `ls /dev/ttyUSB*` (Linux).

### 3. Assign Motor IDs

All motors ship with ID `1`. Assign unique IDs 1–10 one motor at a time:

1. Plug in **one motor** to the U2D2 PHB.
2. Open **Dynamixel Wizard 2.0** → Scan → change ID (1 through 10).
3. Unplug; repeat for next motor.

> Only after all 10 motors have unique IDs should you daisy-chain them together.

### 4. SSH to Raspberry Pi (if running untethered)

```powershell
ssh smartsnake@snakerobo.local
```

Full guide: [`docs/SSH_LOGIN_INSTRUCTIONS.md`](docs/SSH_LOGIN_INSTRUCTIONS.md)

---

## Running the Robot

### Verify All Motors

```bash
python tests/test_dynamixel_ping.py
```

Reports each motor ID found on the bus and explicitly lists any that are missing.

### Calibrate Obstacle Threshold

```bash
python tests/test_motor_feedback.py
```

Streams live Position / Velocity / Current (mA). Gently resist the horn to see the current spike that triggers obstacle detection.

### Start the Snake

```bash
python main.py
```

The snake initialises all motors, then begins the sinusoidal slither gait. Press **Ctrl + C** to halt — all motor torques are disabled cleanly in the `finally` block.

---

## Module Reference

| Module | Class | Description |
|---|---|---|
| [`src/robot_config.py`](src/robot_config.py) | `Config`, `DynamixelAddr` | All hardware constants, tuning parameters, control table addresses |
| [`src/utils.py`](src/utils.py) | — | `to_signed_current()` — XL330 two's complement current conversion |
| [`src/snake_locomotion.py`](src/snake_locomotion.py) | `SnakeKinematics` | Sinusoidal gait: computes goal encoder positions for all joints |
| [`src/obstacle_avoidance.py`](src/obstacle_avoidance.py) | `ObstacleAvoidance` | Current-based state machine; side-aware evasion turn direction |
| [`src/kinematics.py`](src/kinematics.py) | `Kinematics` | Bellows-model curvature wave → joint angles (radians) |
| [`src/servo_driver.py`](src/servo_driver.py) | `ServoDriver` | Hardware abstraction layer; mock simulation backend |
| [`src/torque_controller.py`](src/torque_controller.py) | `TorqueController` | PD torque controller with shape & radius modification modules |

### Gait Parameters (`src/robot_config.py`)

| Parameter | Value | Description |
|---|---|---|
| `NUM_JOINTS` | 10 | Number of motors in daisy chain |
| `ENCODER_CENTER` | 2048 | Neutral position (0° for XL330, range 0–4095) |
| `OBSTACLE_CURRENT_THRESHOLD_MA` | 350 mA | Stall detection threshold |
| `EVASION_REVERSE_DURATION_S` | 2.5 s | Time to reverse before turning |
| `EVASION_TURN_DURATION_S` | 4.0 s | Time in turning gait before resuming |
| `MAX_TORQUE_NM` | 0.52 Nm | XL330 stall torque (per ROBOTIS datasheet @ 5V) |

---

## CAD Files

Designed in **SolidWorks**; exported to STEP and STL for cross-platform use.

| File | Location | Description |
|---|---|---|
| `segment1.SLDPRT / .step / _v1.stl` | `cad/segments/` | Primary body segment |
| `segment1_alt.SLDPRT` | `cad/segments/` | Alternate body segment variant |
| `segment2.SLDPRT / .step / _v1.stl` | `cad/segments/` | Secondary body segment |
| `assembly.SLDASM` | `cad/assembly/` | Full 10-motor robot assembly |
| `XL,XC-330.stp` | `cad/motor-ref/` | Dynamixel motor reference model |

> Print settings: PLA or PETG recommended; 20% infill; 0.2 mm layer height.

---

## Documentation

| Document | Path | Description |
|---|---|---|
| Hardware BOM | [`docs/reports/hardware_bom.md`](docs/reports/hardware_bom.md) | Full parts list with pricing |
| Starter Kit Manual | [`docs/reports/starter_kit_manual.md`](docs/reports/starter_kit_manual.md) | Single-motor first-time setup |
| Wiring Diagram | [`docs/wiring_diagram.md`](docs/wiring_diagram.md) | Power + data flow (Mermaid + text) |
| Raspberry Pi Setup | [`docs/raspberry_pi_setup_guide.md`](docs/raspberry_pi_setup_guide.md) | OS configuration guide |
| SSH Login | [`docs/SSH_LOGIN_INSTRUCTIONS.md`](docs/SSH_LOGIN_INSTRUCTIONS.md) | Connecting to the Pi from Windows |
| Parts & Safety | [`docs/parts_and_safety.md`](docs/parts_and_safety.md) | Handling & safety guidelines |
| Progress Presentation | [`docs/presentations/`](docs/presentations/) | SURGE review slides |
| Datasheets | [`docs/datasheets/`](docs/datasheets/) | XL330 datasheet, Pi pinout |

---

## Team

**SURGE-090 — Smart Snake Robot**  
Indian Institute of Technology Delhi — Summer 2026

| Member | Role |
|---|---|
| Shashank Jangir | Project Lead / Software |
| Bhavesh | Hardware & Mechanical |
| Mahima | Electronics & Wiring |

---

## Acknowledgements

This project was carried out under the **SURGE (Summer Undergraduate Research Grant for Excellence)** programme at **IIT Delhi**. We thank our project supervisor and the Department of Mechanical Engineering for their guidance and laboratory resources.

---

## License

© 2026 SURGE-090 Team, IIT Delhi. All rights reserved.  
This repository is shared for academic and research purposes only.

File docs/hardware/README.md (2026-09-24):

# docs/hardware — power & wiring design (Gen 2, ST3215)

**Current design: split power bus v3** → [`power_split_bus_v3.md`](power_split_bus_v3.md) ·
[`wiring_split_bus_v3.svg`](wiring_split_bus_v3.svg) · build guide [`../4_WIRING_DIAGRAM.md`](../4_WIRING_DIAGRAM.md) ·
parts & budget [`Updated_Hardware_Inventory.md`](Updated_Hardware_Inventory.md).

Older designs are kept here on purpose, so the reasoning behind each change stays visible.

## Design history — what we did before and what we do now

| # | Date | Design | Files | Status | What changed / why we moved on |
|:---:|---|---|---|---|---|
| 0 | 16–19 Aug 2026 | 2× 3S 1500 mAh in parallel (Y-harness, 2 × 15 A fuses) → separate Bus Servo Adapter (Waveshare 25514) → **one daisy chain**, all servo current through the adapter; Mini560 5 V buck for a separate ESP32 (UART on GPIO 17/16) | [`wiring_diagram_v1.svg`](wiring_diagram_v1.svg), [`system_architecture.svg`](system_architecture.svg) | Superseded | Hardware changed to **one** 3S 1800 mAh pack and the **Servo Driver with ESP32** (integrated, UART GPIO 18/19). The diagram itself noted that a single chain at up to 27 A stall needs mid-chain 12 V injection. |
| 1 | 23 Sep 2026 | **Centre-fed:** driver + power tee mid-body, two half-chains of 5, 5 A fuse each; driver fed by 7.5 V buck, its servo +V cut | [`power_centre_fed_v1.md`](power_centre_fed_v1.md), [`wiring_centre_fed_v1.svg`](wiring_centre_fed_v1.svg) | Superseded | Cheapest, but ~0.5–1 V drop to the end servos and the first plug on each side overloads above ~0.6 A per servo. |
| 2 | 23 Sep 2026 | **Split bus v2 (4+3+3):** one DATA line, 12 V trunk injected into 3 groups, 5 A fuse each | [`power_split_bus_v2.md`](power_split_bus_v2.md), [`wiring_split_bus_v2.svg`](wiring_split_bus_v2.svg) | Superseded | A 4-servo group can reach ~3.6 A under heavy load, above the ~3 A plug-pin rating. |
| 3 | 23 Sep 2026 | **Split bus v3 (2+2+2+2+2):** 15 A main fuse → loop key → main line → 5 inject boards, 3 A fuse + 470 µF each | [`power_split_bus_v3.md`](power_split_bus_v3.md), [`wiring_split_bus_v3.svg`](wiring_split_bus_v3.svg) | **Current** | Each plug carries only 2 servos' current, a jam takes out only 2 joints, voltage drop < 0.1 V. Cost: 5 inject boards. Firmware `robot_esp32_v2` soft-starts one group at a time so the 3 A fuses don't trip. |

## Files

| File | What it is |
|---|---|
| `Updated_Hardware_Inventory.md` | Parts on hand, parts to buy, budget, power paths |
| `power_split_bus_v3.md` / `wiring_split_bus_v3.svg` | **Current** power design and drawing |
| `power_split_bus_v2.md` / `wiring_split_bus_v2.svg` | Superseded — 3 groups (4+3+3) |
| `power_centre_fed_v1.md` / `wiring_centre_fed_v1.svg` | Superseded — centre-fed, two half-chains |
| `wiring_diagram_v1.svg` / `system_architecture.svg` | Superseded — first Gen 2 concept (dual LiPo, separate adapter + ESP32) |

The CAD spec for the body segment lives with the model: [`../../gen2-st3215/cad/segments/v6/README.md`](../../gen2-st3215/cad/segments/v6/README.md).

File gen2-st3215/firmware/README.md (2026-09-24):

> **Updated 24 Sep 2026.** What we did before and what we do now is recorded in [What changed](#what-changed) at the end of this file.

PlatformIO (VS Code). The project root is the **repo root** — `platformio.ini`
lives there, with `src_dir = gen2-st3215/firmware`, so open the repo folder in
VS Code and each sketch appears as its own environment.

```
pio run -e spin_all -t upload      # build + flash
pio device monitor -e spin_all     # serial monitor
```

| Env | When to flash |
|---|---|
| `spin_all` | Smoke test: broadcast sweep, runs with all servos still on factory ID 1 |
| `assign_ids` | First real bring-up: **one** ST3215, VIN 6–12.6 V, set IDs 1–10 |
| `usb_servo_bridge` | PC Python (`main.py`, `tests`, `tools/assign_id.py`) |
| `robot_esp32_v2` | **Field firmware of record** (split power bus v3): gait + MPU6050 + ESP-NOW, safe start — see below |
| `robot_esp32` | *Superseded* by `robot_esp32_v2`. Kept for reference only; do not flash on the v3 power bus |
| `base_esp32` | ESP32 #2 on the Pi USB |

Servo UART on the Waveshare driver: GPIO **18 RX / 19 TX**, 1 Mbps. If ping is
silent, swap those pins. Never put Mean Well 5 V on driver VIN.

**Sources are `.cpp`, not `.ino`.** PlatformIO only runs its Arduino
`.ino`→`.cpp` conversion on sketches at the top level of `src_dir`; with one
folder per sketch the `.ino` files were silently skipped and the link failed
with `undefined reference to setup()`. Every file already includes `<Arduino.h>`
and defines its functions before use, so plain C++ compiles unchanged. Keep new
sketches as `.cpp` and give each one its own `[env:...]` block with
`build_src_filter = -<*> +<folder/*>` — without the leading `-<*>` all folders
compile into one binary and collide on `setup()`/`loop()`.

## robot_esp32_v2 — field firmware (flash this one)

Written for **split power bus v3** (`docs/hardware/power_split_bus_v3.md`):
3S LiPo → 15 A fuse → loop key → main line, tapped into 5 groups of 2 servos
(ID 1–2, 3–4, 5–6, 7–8, 9–10), 3 A PTC per tap. The driver board's servo-port
+V is cut, so it sends DATA + GND only.

```
pio run -e robot_esp32_v2 -t upload
pio device monitor -e robot_esp32_v2
```

What it adds over `robot_esp32`:

| Feature | Value |
|---|---|
| Boot state | Torque **OFF** — nothing moves until `RUN` |
| Soft start | Torque on one power group at a time (400 ms apart, slow speed), then amplitude ramps in over 3 s so the PTCs don't trip |
| Joint limit | ±70° (v6 segment mechanical limit ±80°), per-joint `TRIM[]` |
| Torque limit | 70 % |
| Stall detect | 1200 mA for 4 consecutive samples (calibrate on hardware) |
| Low battery stop | 10.2 V (3.4 V/cell) for 3 s |
| Over-temp stop | 70 °C |
| Loop / telemetry | 50 Hz control, 10 Hz telemetry |

Serial commands (115200, end with Enter):

| Command | Action |
|---|---|
| `RUN` | Start slithering (soft start) |
| `STOP` | Torque off, horns go limp |
| `CENTER` | Hold every joint straight — use while fitting horns (only from STOP) |
| `PING` | List servo IDs that answer, with voltage/temperature (only from STOP) |

The telemetry and command structs are unchanged, so `base_esp32` works with
either robot firmware. `robot_esp32_v2/surge_protocol.h` matches
`base_esp32/surge_protocol.h` (and `robot_esp32/surge_protocol.h`). Each sketch keeps
its own copy — if you change the protocol, change all three together.

---

## What changed

### 24 Sep 2026

| Topic | Before | Now | Why |
|---|---|---|---|
| Field firmware | `robot_esp32`: torque on at boot, all servos start together | `robot_esp32_v2`: boots limp, soft start one power group at a time, ±70° joint limits, stop at 10.2 V / 70 °C | With 3 A fuses per pair of servos, starting all 10 servos at once could blow fuses; v2 also adds battery/temperature protection |
| Servo power assumed | 12 V into the driver VIN; the driver board powers the servo bus | Split bus v3: servos fed from the main line in 5 fused groups; driver sends DATA + GND only | Each plug carries only 2 servos' current, a jam takes out only 2 joints, and the voltage drop is almost zero (see `power_split_bus_v3.md`) |
| Shared protocol header | `firmware/include/surge_protocol.h` kept although it had drifted from the sketches' copies | Deleted; each sketch keeps its own matching `surge_protocol.h` | A stale header could cause a silent ESP-NOW struct mismatch between robot and base |

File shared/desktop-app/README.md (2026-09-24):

# SURGE-090 · Desktop Control App (Tkinter)

Native desktop application for controlling the Snake SURGE robot. Built with **Tkinter** and **Matplotlib**, it provides a full control dashboard with path drawing, mathematical path generation, PyBullet simulation integration, live 10-motor telemetry, and path accuracy reporting.

> **Source:** Integrated from the `Snake_SURGE` standalone prototype.

---

## Features

| Feature | Description |
|---|---|
| **GUI Dashboard** | Full Tkinter window (1100×900) with path canvas, telemetry grid, and connection panel |
| **Headless Mode** | Lightweight mode for Raspberry Pi — no GUI, just straight-line slither |
| **Dual Engine** | Switch between PyBullet simulation and ST3215 hardware |
| **Mouse Path Drawing** | Click and drag on the 2D canvas to trace custom paths |
| **Math Path Generator** | Type `sin(x)`, `cos(x)*2`, `exp(-x/5)*sin(x)`, etc. |
| **Zooming Canvas** | Mouse wheel zooms the 2D path canvas in/out |
| **PyBullet Sync** | Simulation sliders in PyBullet 3D window sync back to the Tkinter app |
| **Live Telemetry** | Real-time angle (°), speed, and torque (Nm) for all 10 actuators |
| **Auto-Stop + Report** | Stops when snake reaches path end; pops up Matplotlib accuracy graph |

---

## Usage

### GUI Mode (Laptop / Desktop)

```bash
cd desktop-app
python app.py --gui
```

Opens the full Tkinter dashboard. Choose Simulation or Hardware mode, then:
1. Draw a path with your mouse, or type a math function and click "Generate Path"
2. Click "Connect Engine"
3. Watch the snake follow the path in real-time
4. When the snake reaches the end, an accuracy report auto-opens

### Headless Mode (Raspberry Pi)

```bash
python app.py
```

Runs the snake in a straight line forever using the ST3215 hardware. No GUI libraries needed. Press `Ctrl+C` to stop.

### Headless + Simulation

```bash
python app.py --sim
```

Runs the simulation engine headlessly (useful for testing without hardware or a display).

---

## Dependencies

Requires the `src/` modules from the project root. The app imports:
- `src.snake_locomotion` — Serpenoid gait engine
- `src.path_engine` — Pure pursuit path following
- `src.simulation_interface` — PyBullet digital twin
- `src.st3215_interface` — ST3215 hardware bridge

Additional Python packages:
- `tkinter` (usually bundled with Python)
- `matplotlib` (for accuracy report graphs)
- `pyserial` (for hardware mode)
- `pybullet` (for simulation mode)

---

## See Also

- **Web Dashboard:** [`../web-dashboard/`](../web-dashboard/) — Browser-based alternative (Flask)
- **PyBullet Simulation:** [`../simulation/pybullet/`](../simulation/pybullet/) — Physics engine details
- **App Usage Manual:** [`../../docs/1_APP_USAGE_MANUAL.md`](../../docs/1_APP_USAGE_MANUAL.md) — Detailed operating instructions

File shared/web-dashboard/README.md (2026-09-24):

# SURGE-090 · Web Dashboard (Flask)

Browser-based control dashboard for the Snake SURGE robot. Runs a **Flask** web server with a real-time REST API, 2D trajectory canvas, 3D Three.js viewer, motor telemetry, and simulation parameter tuning — all accessible from any device on the network.

> **Source:** Integrated from the `Snake_SURGE` standalone prototype.

---

## Features

| Feature | Description |
|---|---|
| **Dual Engine Support** | Switch between PyBullet simulation and ST3215 hardware via the web UI |
| **2D Path Canvas** | Draw paths with mouse or generate mathematically (`sin(x)`, `cos(x)`, etc.) |
| **3D Snake Viewer** | Three.js-based real-time 3D visualization of the snake (`/3d` route) |
| **Live Telemetry** | Real-time angle, speed, and torque for all 10 motors |
| **Simulation Sliders** | Tune friction, amplitude, frequency, phase lag, motor force, and sim speed |
| **Path Accuracy Report** | Auto-generates accuracy % and deviation metrics when path is completed |
| **System Stats** | Live CPU, RAM, and temperature monitoring (ideal for Raspberry Pi) |
| **Auto-Stop** | Automatically stops and reports when the snake reaches the end of a target path |

---

## Repository Layout

```
web-dashboard/
├── web_app.py              # Flask server + background physics thread
├── requirements.txt        # Python dependencies
├── templates/
│   ├── index.html          # Main dashboard UI
│   └── 3d_viewer.html      # Three.js 3D snake viewer
└── static/
    ├── script.js           # Client-side canvas, API polling, UI logic
    └── style.css           # Dashboard styling
```

---

## Setup

```bash
cd web-dashboard
pip install -r requirements.txt
```

Dependencies: `flask>=2.0.0`, `psutil>=5.8.0`, `pyserial>=3.5`, `pybullet>=3.2.0`

---

## Running

```bash
python web_app.py
```

Opens on **http://localhost:5000**. Access the 3D viewer at **http://localhost:5000/3d**.

> **On Raspberry Pi:** Access from any device on the same Wi-Fi network using `http://<pi-ip>:5000`

---

## REST API Endpoints

| Method | Endpoint | Description |
|---|---|---|
| `GET` | `/` | Main dashboard HTML |
| `GET` | `/3d` | Three.js 3D viewer HTML |
| `POST` | `/api/connect` | Connect/disconnect engine (`{"engine": "SIM"` or `"ST3215"}`) |
| `POST` | `/api/params` | Set simulation parameters (`fric`, `amp`, `freq`, `phase`, `force`, `speed`) |
| `POST` | `/api/set_path` | Set target path (`{"path": [[x1,y1], [x2,y2], ...]}`) |
| `GET` | `/api/status` | Get running state, robot pose, telemetry, segments, actual path |
| `GET` | `/api/3d_status` | Get 3D segment positions + quaternions for Three.js |
| `GET` | `/api/system_stats` | Get CPU %, RAM %, and Pi temperature |
| `GET` | `/api/report` | Get path accuracy % and deviation metrics |

> Full protocol details: [`../../docs/API_DOCUMENTATION.md`](../../docs/API_DOCUMENTATION.md)

---

## See Also

- **Desktop App:** [`../desktop-app/`](../desktop-app/) — Tkinter desktop control suite (offline use)
- **PyBullet Simulation:** [`../simulation/pybullet/`](../simulation/pybullet/) — Physics engine details
- **API Documentation:** [`../../docs/API_DOCUMENTATION.md`](../../docs/API_DOCUMENTATION.md) — Serial protocol templates

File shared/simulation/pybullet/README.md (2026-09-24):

# SURGE-090 · PyBullet Physics Simulation (Digital Twin)

Full-physics simulation of the 10-segment snake robot using **PyBullet**. Acts as a digital twin for the hardware — same motor interface, same kinematics engine, but running in a physics sandbox with gravity, friction, and collision.

> **Source:** Integrated from the `Snake_SURGE` standalone prototype.

---

## What's In Here

| File | Description |
|---|---|
| `simulation_interface.py` | PyBullet digital twin (213 lines) — loads URDF, supports GUI + headless modes, anisotropic friction, camera tracking, telemetry readback, 3D state export for Three.js |
| `snake.urdf` | 10-segment snake URDF model with visual, collision, and inertial properties for each link + revolute joints |

---

## Requirements

```bash
pip install pybullet>=3.2.0
```

---

## Usage

### From Python

```python
from simulation_interface import SimulationInterface

sim = SimulationInterface(num_motors=10)

# GUI mode (opens 3D window)
success, msg = sim.connect(headless=False)

# Headless mode (no window, faster)
success, msg = sim.connect(headless=True)
```

### GUI Features (non-headless)

When running with `headless=False`, the PyBullet window provides:
- **Camera tracking** — Follow, Top-Down, or Side views via slider
- **Live tuning sliders** — Amplitude, Frequency, Phase Lag, Motor Force, Friction Ratio
- **Ground grid** with 0.5m spacing and axis indicators
- **Head trail** drawn in purple to visualize the path taken
- **Target path** drawn in blue on the ground plane

### Interface Methods

| Method | Description |
|---|---|
| `connect(headless=False)` | Start PyBullet and load the snake URDF |
| `disconnect()` | Close PyBullet |
| `write_positions(angles_dict, max_force)` | Apply target joint angles and step physics |
| `read_telemetry()` | Get virtual load, velocity, position per joint |
| `get_robot_pose()` | Get (X, Y, Yaw) of the snake head |
| `get_all_segment_positions()` | Get (X, Y) tuples for all segments |
| `get_3d_state()` | Get 3D XYZ + Quaternion for Three.js rendering |
| `read_sliders()` | Read PyBullet GUI slider values |
| `update_physics(fric, pov, zoom, pos)` | Update friction, camera, and draw trails |
| `draw_target_path(path)` | Draw a blue path on the ground |

---

## URDF Model

The `snake.urdf` defines a 10-link chain (link0 through link9) connected by 9 revolute joints:
- **Segment size:** 60mm × 55mm × 55mm boxes
- **Joint limits:** ±1.5 radians (~86°)
- **Mass per segment:** 100g
- **Joint axis:** Z (yaw-only, planar motion)

---

## Integration

This simulation engine is used by:
- **Web Dashboard** (`../../web-dashboard/`) — via headless mode for server-side physics
- **Desktop App** (`../../desktop-app/`) — via GUI mode with live PyBullet window
- Both share the same `SimulationInterface` API as the hardware `ST3215Interface`

---

## See Also

- **Wokwi Simulation:** [`../wokwi/`](../wokwi/) — Browser-based ESP32 simulation with SG90 servos
- **Web Dashboard:** [`../../web-dashboard/`](../../web-dashboard/) — Flask web control dashboard
- **Desktop App:** [`../../desktop-app/`](../../desktop-app/) — Tkinter control suite

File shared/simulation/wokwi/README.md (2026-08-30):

# SURGE-090 · ESP32 Serpentine Robot Wokwi Simulation

Interactive browser simulation of the 5-segment snake robot on **Wokwi**:  
🔗 **[wokwi.com/projects/467623718124707841](https://wokwi.com/projects/467623718124707841)**

---

## Hardware Configuration (`diagram.json`)

The simulation runs on an **ESP32 DevKit v1** connected to:
- **5× SG90 PWM Servos** on GPIOs `26, 27, 14, 12, 13`
- **HC-SR04 Ultrasonic Distance Sensor** on `TRIG = GPIO 5`, `ECHO = GPIO 18`
- **MPU6050 6-DOF IMU** on I²C (`SDA = GPIO 21`, `SCL = GPIO 22`, addr `0x68`)
- **SSD1306 128×64 I²C OLED** on I²C (`SDA = GPIO 21`, `SCL = GPIO 22`, addr `0x3C`)

---

## Key Firmware Features (`sketch.ino`)

1. **Serpenoid Gait Engine:**
   $$\text{angle}_i = \text{center} + \text{trim}_i + \text{bias} + \text{dir}_i \cdot A \cdot \sin(\text{phase} + d \cdot i \cdot \text{lag})$$
   - Real-time travelling wave propagation across all 5 joint servos.
   - Modes: `FWD`, `REV`, `LEFT`, `RIGHT`, `IDLE`, `AUTO` (autonomous collision avoidance).

2. **Sensorless / Ultrasonic Collision & Safety Stack:**
   - **Exponential smoothing** on distance ($\alpha = 0.4$) to filter ultrasonic noise.
   - **Hysteresis switching:** triggers avoidance below $20\text{ cm}$, resumes normal slither above $25\text{ cm}$.
   - **MPU6050 flip detection:** pauses gait motion if pitch/roll indicates the robot tipped over.
   - **Graceful degradation:** missing OLED or IMU will not block startup or gait execution.

3. **Non-blocking Scheduling:**
   - Uses `millis()` timers for servos (50 Hz), sensors (10 Hz), and OLED display (5 Hz) with zero `delay()` stalls.

4. **Live Serial Tuning Console (115200 baud):**
   Type commands into the Serial Monitor to tune gait parameters live:
   - `f` / `b` / `l` / `r` / `s` / `a`: Forward / Reverse / Left / Right / Stop / Auto
   - `A<deg>`: Set wave amplitude (e.g. `A40`)
   - `S<speed>`: Set gait frequency / speed (e.g. `S1.2`)
   - `W<deg>`: Set phase lag between joints (e.g. `W45`)
   - `T<deg>`: Set turn bias offset (e.g. `T25`)
   - `C<deg>`: Set center trim position (e.g. `C90`)
   - `?`: Print current configuration and help menu

---

## How to Run

1. Open **[wokwi.com/projects/467623718124707841](https://wokwi.com/projects/467623718124707841)** directly, or copy `diagram.json`, `sketch.ino`, and `libraries.txt` into a new Wokwi ESP32 project.
2. Click **Start Simulation**.
3. Adjust the HC-SR04 distance slider to test obstacle detection and evasion.
4. Interact via the Serial Monitor at 115200 baud.

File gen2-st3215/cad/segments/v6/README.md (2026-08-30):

# segment_v6 — SURGE-090 snake robot segment

This is the ST3215 segment, rebuilt from v4's structure after v5 regressed. It is
a parametric CadQuery model rather than a SolidWorks part, so every dimension is
traceable to a named constant and the file refuses to export if its own
assumptions stop holding.

```
segment_v6.py      the model, with a self-check block that raises SystemExit
probe_st3215.py    run this against ST3215.step BEFORE printing
README.md          this file
```

## Why v6 exists

v4 and v5 are close relatives — v5 is essentially v4 with a wider yoke rectangle,
and the two share a bounding box. v5's early sidewall bug is fixed and should not
be re-reported. What neither of them fixes is a set of three defects that run
through both, and that only showed up when the parts were measured rather than
looked at.

The critical one is ground contact. The bottom yoke plate sits at z = −3.45 while
the belly scale tips sit at −3.00, so the plate hangs 0.45 mm **below** the
scales and the robot rests on two smooth discs. Measured downward-facing area is
1006 mm² of plate against 66 mm² of scale: about 94% of ground contact is the one
surface that was never meant to touch, and the friction feature is inert.

The second is that the scales point the wrong way. They are swept along Y, so
they resist fore-aft sliding and slide freely sideways. Lateral undulation needs
the opposite — grip across the body, slide along it — so the feature is not
merely inert but backwards, and it actively fights the reverse manoeuvre in the
gait state machine.

The third is that the motor has no positive retention at all. It sits in a 0.4 mm
slip-fit pocket, open at the top, and lifts straight out. The lightening windows
remove most of the cradle sidewall over the mid-height band, and the cable hole
leaves roughly a millimetre of rear wall beside it.

v6 addresses all three, and the self-check block now asserts the first rather
than trusting it: it enumerates every face lying at the model's minimum z and
requires that they are exactly the keel lands, by count and by area. That check
is what makes the ground-contact defect impossible to reintroduce silently.

## The datum frame

Everything in the file is expressed in one frame, and misreading it is the
easiest way to break the part.

The origin sits on **this** segment's rear joint axis, which is the axis of the
*previous* segment's output shaft. `+x` runs forward toward the head. `+z` is up.
The joint axes are therefore **vertical**, which is what makes the torque budget
comfortable: gravity contributes exactly zero joint torque, and the motors only
ever fight friction.

`PITCH = 58.0` is the axis-to-axis spacing, so this segment's own output axis is
at `x = 58.0`, and the next segment's origin coincides with it. `z = 0` is a
label, not a surface: it sits 0.25 mm below the tip of the motor's idler boss.
No geometry references `z = 0` directly — every feature is defined against
`SEAT_Z`, `HUB_Z` or `HORN_Z` — so the label costs nothing, but do not assume it
lies on a face.

## Motor datums, and where they came from

The vendor STEP file is an assembly whose sub-part frames are **untransformed**.
Sub-parts sit at their authoring origins, not their assembled positions, so
measuring a feature's *position* in that file gives a number that has nothing to
do with the real motor. `probe_st3215.py` matches the case by **shape** for
exactly this reason. This is a trap worth remembering: it produced several
confident, wrong numbers before it was spotted.

The authoritative source is instead `../../motor-ref/ST3215.dxf`, read as vector
data rather than measured off a rendering. Two cautions apply there too. First,
filter to the visible layer (`可见`): dimension extension lines otherwise read as
part edges, and one of them looks convincingly like a face. Second, dimension
arrowhead ticks are short line segments that cluster near real geometry — an
arrowhead pair 19.200 mm apart is not the Ø19.2 disc, and mistaking it moves the
shaft axis by 0.7 mm.

Read properly, the case silhouette is 45.223 mm long and the shaft axis falls
10.112 mm from the horn-end face and 35.112 mm from the rear. The topmost feature
is the Ø19.2 horn disc, centred on that axis; the bottommost is a Ø6.00 boss
standing 0.30 mm below the idler face. Both large faces carry a four-hole pattern
at exactly ±7.00 mm in both axes about the disc centre, and both carry a Ø19.2
disc — which is the geometric precondition for the double-shear load path below.

| quantity | value | source |
|---|---|---|
| case envelope | 45.22 × 24.72 × 37.25 | DXF, dimension definition points |
| shaft axis from horn-end face | 10.112 | DXF silhouette, corroborated by the 37.25 dimension |
| bolt circle radius, both faces | 7.00 | DXF, four Ø2.5 circles per face |
| horn / idler disc | Ø19.2 both faces | DXF |
| idler centre boss | Ø6.00, 0.30 proud | DXF silhouette |
| lowest case face | z = 0.70 over x 28.80..38.23 | DXF, agrees with v4 to 0.03 mm |
| mounting terrace | z = 4.10 over x 25.03..52.30 | DXF |
| stall torque | 2.94 N·m at 12 V | datasheet |

`HORN_Z = 37.80` looks wrong against the datasheet's 37.25 and is not. The 37.25
is measured idler-face-to-horn-face, and `37.80 − 0.55 = 37.25` exactly.

## The terraced underside, and the retention screws

The case underside is **not flat**. It steps down in three terraces, and the
lowest face is only 9.43 mm long. v6's first cut ignored this: it drove two
retention screws up through the floor at `x = 25.25`, where the case never comes
down to the seat plane at all — it is 3.40 mm above it. Those screws crossed an
air gap and clamped nothing, and both the model and its verifier passed, because
neither of them knew the underside profile.

The fix is two ribs that rise from the floor to 4.05, a hair under the 4.10
terrace, each bonded to both the floor and the rear pocket wall so it is a wall
rather than a free-standing post — strong in the exact direction the screw pulls,
and printable without support. The 0.70 pad still beds on the floor forward of
the ribs, which is what stops the motor pitching about the screw line. The two
contacts are conformal rather than over-constrained: the case meets plastic at
both heights simultaneously because the plastic was cut to the measured profile.

The front screw pair cannot be used at all. It lands at `x = 49.70`, which is
13.19 mm from the output axis, inside the crescent cleared for the neighbour's
yoke. There is no material there to put a hole in. The motor's front end is
already clamped by four screws into the next segment's yoke plates, so it cannot
lift out regardless.

The fasteners are **M2, not M2.5**. The drawing renders every case hole as a
concentric Ø1.6 / Ø2.0 pair, which is the tap-drill and nominal pair for M2;
M2.5 would be Ø2.05 / Ø2.5. This change also bought clearance: the Ø4.0
countersink leaves 0.75 mm to the nearest keel where the Ø5.0 head left 0.25.

One question is genuinely unresolved. The two case faces carry **different** hole
patterns — 24.45 mm pitch on one, 20.70 mm on the other — and the drawing labels
neither. The default assumes 24.45, because both of its holes then land on the
single 4.10 terrace, which is what a mounting interface looks like, whereas the
20.70 pattern splits its holes across two terraces and puts one 0.20 mm inside a
pad edge. If your motor measures 20.70, the ribs must be **deleted**, not moved:
at `x = 29.00` the case comes all the way down to the seat, so a rib there would
lift the motor off its pad. `verify_v6.py` checks precisely this and fails loudly
if one constant is changed without the other. `probe_st3215.py` item 4 turns this
into a single caliper reading.

## Load path

Both yoke plates bolt to the neighbour's motor: the top plate to the Ø19.2 horn
and the bottom plate to the Ø19.2 rear idler disc, on the same R7.00 circle. The
joint therefore runs in **double shear** rather than cantilevering off the horn
alone, which is what keeps a 670 mm chain from sagging at every joint. At stall
that is 105 N per bolt, 21.4 MPa in the screws and 9.7 / 11.1 MPa bearing in the
PLA — a factor of five on the plastic, which is the limiting material.

This entire scheme rests on one physical assumption: **that the rear idler disc
rotates with the horn.** If it is fixed to the case, bolting both plates locks
the joint solid and the first command will stall a motor or strip a gear. This is
item 1 on the probe checklist and it takes five seconds to check by hand.

## Friction and gait

Seven keels run **along** the body at y = 0, ±3.20, ±6.40, ±14.75, tapering from
2.20 mm at the base to 1.10 mm at the tip over 1.60 mm of height — a 19° flank,
comfortably self-supporting. Running lengthwise, they resist sideways slip and
slide forward, which is the anisotropy lateral undulation actually needs. The
outermost pair sits at ±14.75 of a 16.50 half-width, giving roll stability
without exceeding the body envelope. Contact is 200 mm² per segment, 2202 mm²
across eleven, about 4.9 kPa — low enough not to mark a floor.

The torque numbers say the gait is easy and one particular manoeuvre is not. At
µ = 0.8, undulation needs 0.207 N·m, 7% of stall. Pivoting the whole grounded
body about one joint needs 2.78 N·m, **95% of stall.** Do not slew a stationary
robot on the ground; lift it or let it undulate into position. `verify_v6.py`
captures this as an explicit warning rather than a failure, because it is a
constraint on how the robot is driven, not a defect in the part.

## Chain geometry

Eleven segments give ten joints: `10 × 58.0 = 580 mm` axis-to-axis, and 670 mm
overall from the rear yoke at −15.0 to the head nose at 654.5. Note that
`segment_v5.py` prints 638 mm for this, which is wrong; so was an earlier figure
in the v6 planning notes. 580 and 670 are the numbers.

## Printing

PLA, 0.4 mm nozzle, 0.42 mm extrusion width. Every wall in the part was checked
against three extrusions minimum, and the thinnest — the rib wall beside the
screw hole — comes out at 1.31 mm, or 3.1 passes.

Print Z-up as modelled. The keel lands form the first layer, and the floor then
bridges off them; the longest unsupported span is 6.15 mm, between the y = ±6.40
and y = ±14.75 keels, which PLA bridges without help. Support is needed **only**
under the two rear yoke plates, which cantilever past the body. The Ø8 centre
bores and the R7.00 bolt holes are modelled at nominal; ream them if your printer
runs tight, because a bolt forced into an undersized hole in PLA will split the
plate along the layer lines.

Sand the z = 37.80 face flat before assembly. It is the face the next segment's
bottom yoke lands on, and a print artifact there tilts the whole joint.

## Before you print

`probe_st3215.py` compares fourteen assumed motor dimensions against the vendor
STEP and exits non-zero if any is unconfirmed. It then prints five things the
geometry cannot settle: whether the idler disc rotates, whether the case takes
M2 and how deep, what a motor actually weighs (60 g is assumed, and it sets the
whole torque budget), which face carries which screw pattern, and whether the
underside really is terraced as measured.

Run it, then run `segment_v6.py`. The model exports `snake_segment_v6.step` and
`.stl` only if its own checks pass; on failure it raises `SystemExit` listing
what broke rather than writing a part that looks fine and is not.

## Verification status

The dimensional model is independently verified: a separate checker reproduces
the geometry as per-band footprint masks and brute-forces the joint sweep from
−45° to +45° against both neighbours, plus wall thicknesses, bridging, ground
contact, load paths and the chain arithmetic — 49 checks, all passing, with fault
injection proving the collision detector, the relief sizing and the new
retention check all actually fire when fed a defect. A parameter-drift guard
diffs the 56 constants shared between model and checker so the checker cannot
drift into validating a part that was never built.

What has **not** been exercised is CadQuery itself. The sandbox this was written
in could not install it, so the model's API calls have never run. The dimensions
are sound; the possibility of a CadQuery-level error on first execution is real.
Run it and read the self-check output.

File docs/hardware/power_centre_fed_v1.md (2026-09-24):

# SURGE-090 — Centre-fed servo power (cheaper option), v1 (2026-09-23)

Controller: Waveshare Servo Driver with ESP32 (6–12 V in, 2 servo ports on one UART).
Load: 10 × ST3215 (0.2 A no-load, ~0.9 A rated, 2.7 A stall). Pack: 3S LiPo (12.6 V full).

## Rule
The board handles data only. Servo current goes battery → centre power tee → two half-chains,
never through the board's barrel jack or its traces.

## Topology
- Board + power tee sit on a deck over the middle joint (between servo 5 and 6), with the battery there too so the mass is centred.
- Chain A: tee → ID5 → ID4 → ID3 → ID2 → ID1 (toward the head)
- Chain B: tee → ID6 → ID7 → ID8 → ID9 → ID10 (toward the tail)
- Both ports share the same UART, so IDs 1–10 and the firmware stay unchanged.

## Power tee (small perfboard)
Inputs: +12 V/GND from loop key (16–18 AWG); DATA + GND from ONE board servo port (+V pin of that lead cut/insulated).
Outputs: two 5264-style 3-pin headers (GND / +12 V / DATA), each +12 V via its own 5 A blade fuse.
Also: 1000 µF 25 V electrolytic across +12/GND on the tee.
Board VIN: small adjustable buck set to 7.5 V (board max 12 V; 3S reaches 12.6 V). Board VIN no longer
needs to match the servo voltage because the board's +V no longer reaches the servos.
All grounds are common.

## Cables
- Tee → first servo each side: custom 22 AWG silicone lead, ~15 cm (30 mm slack for ±80°).
- All other links: stock 15 cm leads (assumed 24–26 AWG).

## Numbers (26 AWG stock leads, 22 AWG first link, ~10 mΩ per contact)
| per-servo avg | current per side | drop to tail servo | first-link loss |
|---|---|---|---|
| 0.3 A | 1.5 A | 0.32 V | 0.13 W |
| 0.5 A | 2.5 A | 0.54 V | 0.35 W |
| 0.9 A (heavy) | 4.5 A | 0.97 V | 1.13 W |
The 5264 contact is rated about 3 A. Sustained current above ~0.6 A per servo overloads the first plug on each side, so limit torque in firmware.

## Firmware guards
- Torque limit ~70 % (RAM torque-limit register) during gait development.
- Poll present current + voltage of every servo; stop the gait if a side's sum is > 3 A for > 2 s or any servo is < 10 V.
- Use phase-offset serpentine (travelling wave) so joints don't peak at the same moment.

## Bring-up tests
1. Tee alone: 12.x V on both headers, fuses intact; buck = 7.5 V before board.
2. One servo per side, then full chains; slow sine.
3. Under gait: meter at ID1 and ID10 ≥ 11 V on a full pack.
4. After 5 min of gait: first-link plugs only warm to touch (< ~50 °C).
If step 3/4 fails, add one +12 V injection at ID2/ID9 (upgrade to full split bus).

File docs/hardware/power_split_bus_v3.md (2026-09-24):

# SURGE-090 — Split power bus v3 (2+2+2+2+2), 2026-09-23
Replaces v2 (4+3+3). Diagram: `wiring_split_bus_v3.svg`.

## Decision
One controller (Servo Driver with ESP32) drives ONE continuous DATA wire to all 10 ST3215 servos on a single UART.
Power is injected into **5 groups of 2 servos**, each fed from the main 12 V line through its own fuse.
No extra bus-servo driver per group. A group only needs power, not another driver.

## Groups
| Group | Servos | Inject board sits before |
|---|---|---|
| G1 | ID1–ID2 | ID1 (next to the controller) |
| G2 | ID3–ID4 | ID3 |
| G3 | ID5–ID6 | ID5 |
| G4 | ID7–ID8 | ID7 |
| G5 | ID9–ID10 | ID9 |

## Wiring
- **Main power line:** +12 V / GND, 16–18 AWG silicone. Battery (3S LiPo) → 15 A fuse → XT60 loop key → along the whole body, with ~30 mm slack at every joint.
- **Controller:** a small buck set to 7.5 V, fed from the main line, goes to the DC jack. Servo Port 1 lead: GND + DATA only, **+V wire cut and taped**. Port 2 stays empty.
- **Each inject board** (small perfboard, 5 in total):
  - IN from previous servo/controller: GND → through, DATA → through, **+V → cut ✕**
  - IN from main line: +12 V via **3 A fuse** → +V out; GND → GND out
  - OUT (3-pin plug) to the group's first servo: +12 V · GND · DATA
  - 470 µF 25 V capacitor across +12 V / GND
- Tap wires from the main line to each inject board: 20–22 AWG, short.
- DATA and GND are continuous from the controller to ID10. +12 V is broken before every inject board.

## Numbers (per group of 2 servos)
| Condition | Current | Note |
|---|---|---|
| Walking | ~0.6–1.0 A | well under ~3 A plug-pin rating |
| Heavy load | ≤ 1.8 A | OK |
| Both servos stalled | 5.4 A | the 3 A fuse blows, which protects the plugs |
| Voltage drop to the 2nd servo | < 0.1 V | negligible |
Total from the battery while walking is ~3–5 A; the 15 A main fuse and 16–18 AWG main line cover it.

## Parts (in addition to the v2 list)
- 5 × small perfboard inject boards
- 5 × 3 A fuses (mini blade + inline holder), or 5 × 3 A PTC resettable fuses (smaller, self-resetting)
- 5 × 470 µF 25 V capacitors
- 5 × 3-pin 5264-style plug pairs, 20–22 AWG silicone for the taps

If fuses trip when every servo moves at once at power-up, ramp the servos to their start pose slowly (or use 4 A fuses).

## Trade-offs vs 4+3+3
- Better: each plug carries only 2 servos' current; a jam takes out only 2 joints; almost no voltage drop.
- Costs: 5 inject boards instead of 3, which means more solder joints and connectors that can fail, and a fuse to fit at every second joint. Check the Ø8 cable tunnel fits 2 main-line wires + the servo lead.

## Build order
1. Battery → fuse → key → main line: meter reads 12.x V.
2. Set buck to 7.5 V, then connect the controller.
3. Group 1 only (ID1–2) → test each servo by ID.
4. Add groups 2 → 5 one at a time, checking 12 V at each inject board.
5. Slow sine gait; every servo reads ≥ 11.7 V (read Present Voltage from each servo).

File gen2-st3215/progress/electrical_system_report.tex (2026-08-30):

\documentclass[11pt,a4paper]{article}

% --- Packages ---
\usepackage[utf8]{inputenc}
\usepackage[T1]{fontenc}
\usepackage{lmodern}
\usepackage[margin=1in,headheight=14pt]{geometry}
\usepackage{amsmath,amssymb}
\usepackage{newunicodechar}
\newunicodechar{₹}{Rs.\,}
\usepackage{booktabs}
\usepackage{tabularx}
\usepackage{array}
\usepackage{listings}
\usepackage{xcolor}
\usepackage{fancyhdr}
\usepackage{titlesec}
\usepackage{enumitem}
\usepackage{tcolorbox}
\tcbuselibrary{skins,breakable}
\usepackage{microtype}
\usepackage{hyperref}
\usepackage{bookmark}

% --- Color Palette ---
\definecolor{primary}{RGB}{18, 52, 86}      % Deep Navy
\definecolor{secondary}{RGB}{30, 115, 190}  % Bright Blue
\definecolor{accent}{RGB}{220, 80, 50}      % Accent Amber/Red
\definecolor{darkgray}{RGB}{50, 50, 50}
\definecolor{lightgray}{RGB}{245, 247, 250}
\definecolor{bordercolor}{RGB}{210, 215, 225}
\definecolor{codebg}{RGB}{248, 249, 251}
\definecolor{codeframe}{RGB}{220, 225, 230}
\definecolor{codegreen}{RGB}{46, 139, 87}
\definecolor{codegray}{RGB}{120, 120, 120}
\definecolor{codepurple}{RGB}{138, 43, 226}

% --- Hyperref Setup ---
\hypersetup{
    colorlinks=true,
    linkcolor=secondary,
    citecolor=secondary,
    urlcolor=secondary,
    pdfauthor={SURGE-090 Project Team},
    pdftitle={Smart Snake Robot - Complete Electrical System},
    pdfsubject={Electrical Architecture, Component Specs, Wiring, and Firmware},
    pdfkeywords={Snake Robot, ESP32, ST3215, ESP-NOW, LiPo, Raspberry Pi 5}
}

% --- Code Listing Setup ---
\lstdefinestyle{cppstyle}{
    backgroundcolor=\color{codebg},
    commentstyle=\color{codegreen}\itshape,
    keywordstyle=\color{secondary}\bfseries,
    numberstyle=\tiny\color{codegray},
    stringstyle=\color{codepurple},
    basicstyle=\ttfamily\footnotesize,
    breakatwhitespace=false,
    breaklines=true,
    captionpos=b,
    keepspaces=true,
    numbers=left,
    numbersep=7pt,
    showspaces=false,
    showstringspaces=false,
    showtabs=false,
    tabsize=2,
    frame=single,
    rulecolor=\color{codeframe},
    xleftmargin=12pt,
    framexleftmargin=8pt,
    columns=fullflexible
}
\lstset{style=cppstyle}

% --- Callout Box Styles ---
\newtcolorbox{alertbox}[2][]{
    enhanced,
    colback=red!5!white,
    colframe=red!75!black,
    fonttitle=\bfseries,
    title={#2},
    arc=3mm,
    boxrule=1pt,
    leftrule=5pt,
    breakable,
    #1
}

\newtcolorbox{infobox}[2][]{
    enhanced,
    colback=secondary!5!white,
    colframe=secondary!85!black,
    fonttitle=\bfseries,
    title={#2},
    arc=3mm,
    boxrule=1pt,
    leftrule=5pt,
    breakable,
    #1
}

\newtcolorbox{specbox}[2][]{
    enhanced,
    colback=lightgray,
    colframe=primary,
    fonttitle=\bfseries,
    title={#2},
    arc=2mm,
    boxrule=0.8pt,
    breakable,
    #1
}

% --- Section Styling ---
\titleformat{\section}{\Large\bfseries\color{primary}}{\thesection}{1em}{}[\titlerule]
\titleformat{\subsection}{\large\bfseries\color{secondary}}{\thesubsection}{1em}{}
\titleformat{\subsubsection}{\normalsize\bfseries\color{darkgray}}{\thesubsubsection}{1em}{}

% --- Header & Footer ---
\pagestyle{fancy}
\fancyhf{}
\fancyhead[L]{\small\color{darkgray}\textbf{SURGE-090} $\cdot$ Smart Snake Robot Electrical System}
\fancyhead[R]{\small\color{darkgray}August 2026}
\fancyfoot[L]{\small\color{darkgray}Dual 3S LiPo $\cdot$ 10$\times$ ST3215 $\cdot$ ESP32 $\cdot$ ESP-NOW}
\fancyfoot[R]{\small\thepage}
\renewcommand{\headrulewidth}{0.4pt}
\renewcommand{\footrulewidth}{0.4pt}

% --- Document Content ---
\begin{document}

% --- Title Block ---
\begin{center}
    {\LARGE \textbf{\color{primary} Smart Snake Robot --- Complete Electrical System}}\\[0.4em]
    {\large \textbf{SURGE-090} $\cdot$ August 2026}\\[0.3em]
    {\normalsize \color{darkgray} Dual 3S LiPo $\cdot$ 10$\times$ Waveshare ST3215 Servos $\cdot$ ESP32 Onboard $\cdot$ ESP-NOW to Raspberry Pi 5 Base Station}
\end{center}

\vspace{0.8em}
\hrule height 1.5pt
\vspace{1.2em}

% --- Executive Summary ---
\section*{Executive Summary}
This document consolidates all electrical architecture, component specifications, wiring details, safety protocols, and system integration for the Smart Snake Robot project. The system has been comprehensively redesigned from the original Dynamixel XL330 + Raspberry Pi 5 onboard architecture to a lightweight, modular dual-controller approach:
\begin{itemize}[leftmargin=1.5em, itemsep=0.2em]
    \item \textbf{Onboard Compute:} An ESP32 microcontroller mounted directly on the robot running real-time central pattern generator (CPG) gait control, sensor fusion, and high-speed servo bus communication.
    \item \textbf{Base Station:} A Raspberry Pi 5 operating as the high-level supervisory node, executing user interfaces, motion planning, and real-time telemetry dashboards.
    \item \textbf{Wireless Link:} ESP-NOW peer-to-peer 2.4\,GHz link between the onboard ESP32 and a dedicated base station ESP32 radio bridge connected via USB serial to the Raspberry Pi 5.
\end{itemize}

\begin{infobox}{Key Decision Drivers}
\begin{itemize}[leftmargin=1.2em, itemsep=0.2em]
    \item \textbf{Space \& Mass Constraints:} Internal volume and payload capacity on the segmented snake robot chassis preclude mounting the Raspberry Pi 5 onboard.
    \item \textbf{High Torque \& Availability:} Waveshare ST3215 serial bus servos deliver over $6\times$ the torque of the original XL330 motors at approximately $1/3$ the cost and are readily sourced in India.
    \item \textbf{Zero-Infrastructure Wireless:} ESP-NOW delivers ultra-low-latency ($<10\,\text{ms}$) deterministic communication without requiring external Wi-Fi routers or access points.
\end{itemize}
\end{infobox}

\tableofcontents
\vspace{1.5em}
\newpage

% --- 1. Hardware Inventory ---
\section{Hardware Inventory --- Keep / Return}

\subsection{Keep These (Final System)}
\begin{description}[leftmargin=1.8em, itemsep=0.4em]
    \item[\textbf{Core Motors \& Driver:}]
    \begin{itemize}[leftmargin=1.2em, itemsep=0.15em]
        \item 10$\times$ Waveshare ST3215 Smart Servos (6.0--12.6\,V, 1\,Mbps half-duplex TTL, 2.7\,A stall, 30\,kg$\cdot$cm torque at 12\,V).
        \item Bus Servo Adapter (A) --- Waveshare SKU 25514 (9--12.6\,V input, UART control, automated TTL direction switching, servo daisy-chain output).
    \end{itemize}

    \item[\textbf{Power Supply \& Distribution:}]
    \begin{itemize}[leftmargin=1.2em, itemsep=0.15em]
        \item 2$\times$ Orange 3S LiPo 1500\,mAh 30C battery packs (XT60 connectors, $\sim$₹1,219 each).
        \item Mini560-5V synchronous step-down buck converter (high efficiency, up to 3\,A continuous, $\sim$₹150).
        \item 2$\times$ LiPo Low-Voltage Buzzer Alarms with configurable threshold set to 3.4\,V/cell ($\sim$₹100 each).
        \item 2$\times$ 15\,A Mini Blade Fuses + in-line waterproof fuse holders ($\sim$₹100).
        \item XT60 Loop Key (serves as the spark-safe master emergency power disconnect, $\sim$₹150).
        \item 16\,AWG high-strand silicone wire + XT60 parallel Y-harness pigtails ($\sim$₹300).
        \item 1000\,\textmu F 25\,V Low-ESR electrolytic filter capacitor ($\sim$₹30).
        \item iMAX B6 professional balance charger/discharger ($\sim$₹1,500).
    \end{itemize}

    \item[\textbf{Microcontrollers \& Compute:}]
    \begin{itemize}[leftmargin=1.2em, itemsep=0.15em]
        \item \textbf{ESP32 Dev Board \#1 (Onboard Robot):} Central gait generator, sensor polling, UART servo master, ESP-NOW transmitter.
        \item \textbf{ESP32 Dev Board \#2 (Base Station Bridge):} Dedicated ESP-NOW transceiver, USB-UART bridge to Raspberry Pi 5.
        \item \textbf{Raspberry Pi 5 (8GB RAM):} Base station supervisor, trajectory planning, telemetry visualization, web UI / ROS2 nodes.
    \end{itemize}

    \item[\textbf{Sensors:}]
    \begin{itemize}[leftmargin=1.2em, itemsep=0.15em]
        \item MPU6050 6-DoF IMU (GY-521 module, $\text{I}^2\text{C}$ address \texttt{0x68}, posture/orientation tracking).
        \item HC-SR04P Ultrasonic Sensor (\textbf{3.3\,V wide-voltage version}, safe for direct ESP32 GPIO, obstacle avoidance).
    \end{itemize}

    \item[\textbf{Cables \& Fasteners:}]
    \begin{itemize}[leftmargin=1.2em, itemsep=0.15em]
        \item 10$\times$ ST-series 3-pin daisy-chain bus cables (+12\,V / GND / DATA) + 3 spare cables.
        \item Silicone Dupont hookup jumpers, heat-shrink tubing, braided sleeving.
        \item Micro-USB / USB-C interface cables for programming and base station connectivity.
    \end{itemize}
\end{description}

\subsection{Return to Supplier (Dynamixel-Era Components)}
The following components from the legacy design are deprecated and should be returned or repurposed:
\begin{itemize}[leftmargin=1.5em, itemsep=0.25em]
    \item \textbf{Dynamixel XL330 Servos:} Inadequate torque for 10-link body load; high supply lead times in India; protocol incompatible with ST3215 bus.
    \item \textbf{ROBOTIS U2D2 Interface \& Power Hub:} Dynamixel-exclusive TTL pinout and proprietary protocol converter.
    \item \textbf{Dynamixel Communication Cables:} Custom JST connectors incompatible with Waveshare ST-series sockets.
    \item \textbf{5\,V Standalone Power Supply:} Incompatible voltage level; ST3215 motors require 12\,V nominal rail.
    \item \textbf{12V$\to$5V 5\,A Buck Converter:} Bulky footprint; replaced with ultra-compact Mini560 (3\,A).
    \item \textbf{XT60 to 5.5\,mm Barrel Jack Cable:} Deprecated in favor of direct screw-terminal block connections.
\end{itemize}

% --- 2. Component Specifications ---
\section{Component Specifications}

\subsection{Waveshare ST3215 Smart Serial Servo}
\begin{table}[h!]
\centering
\small
\renewcommand{\arraystretch}{1.2}
\begin{tabularx}{\textwidth}{l X}
\toprule
\textbf{Parameter} & \textbf{Specification / Operating Limits} \\
\midrule
Operating Voltage Range & 6.0\,V -- 12.6\,V (Nominal: 11.1\,V -- 12.0\,V) \\
Stall Torque & 30\,kg$\cdot$cm ($\approx 2.94\,\text{N}\cdot\text{m}$) @ 12\,V \\
Stall Current & 2.7\,A per servo @ 12\,V \\
Continuous Operating Current & $\approx 1.0\,\text{A} - 1.5\,\text{A}$ under nominal snake locomotion \\
No-Load Speed & 0.222\,sec/60$^\circ$ (45\,RPM) @ 12\,V \\
Communication Protocol & Feetech SCServo Half-Duplex Asynchronous Serial TTL \\
Baud Rate & 1,000,000\,bps (1\,Mbps) default \\
Addressing Capability & Up to 253 unique IDs on a single daisy-chain bus \\
Position Sensor & 12-bit Contactless Magnetic Encoder (0.088$^\circ$ resolution, 360$^\circ$ multi-turn) \\
Real-Time Telemetry & Position, Velocity, Load/Current, Voltage, Internal Temperature \\
\bottomrule
\end{tabularx}
\caption{Electrical and mechanical specifications of Waveshare ST3215 servo.}
\end{table}

\subsection{Bus Servo Adapter (A) --- Waveshare SKU 25514}
\begin{itemize}[leftmargin=1.5em, itemsep=0.2em]
    \item \textbf{Power Input:} 9.0\,V -- 12.6\,V via heavy-duty 2-pin screw terminal.
    \item \textbf{Logic Interface:} Microcontroller UART interface (TX, RX, 5V/3.3V, GND).
    \item \textbf{Automatic Flow Direction Control:} Onboard hardware direction-switching circuit enables transparent half-duplex single-wire TTL serial communication from full-duplex MCU UART without requiring manual GPIO direction pin manipulation.
    \item \textbf{Servo Outputs:} Dual 3-pin standard ST-bus ports wired in parallel for daisy-chain distribution.
\end{itemize}

\subsection{Orange 3S LiPo 1500 mAh 30C Battery}
\begin{itemize}[leftmargin=1.5em, itemsep=0.2em]
    \item \textbf{Chemistry \& Configuration:} Lithium Polymer (LiPo), 3S1P (3 series cells).
    \item \textbf{Nominal Voltage:} 11.1\,V ($3.7\,\text{V}/\text{cell}$).
    \item \textbf{Fully Charged Voltage:} 12.6\,V ($4.2\,\text{V}/\text{cell}$).
    \item \textbf{Low-Voltage Cutoff Limit:} 10.2\,V total ($3.4\,\text{V}/\text{cell}$) --- hardware alarm trigger.
    \item \textbf{Capacity \& Continuous Discharge:} 1500\,mAh @ 30C $= 45\,\text{A}$ continuous per pack.
    \item \textbf{Peak Burst Discharge (10\,s):} 50C $= 75\,\text{A}$ burst per pack.
    \item \textbf{Main Discharge Connector:} Genuine XT60 with high-temperature nylon housing.
\end{itemize}

\subsection{Mini560-5V Step-Down Synchronous Buck Converter}
\begin{itemize}[leftmargin=1.5em, itemsep=0.2em]
    \item \textbf{Input Range:} 6.0\,V -- 32.0\,V (operating on 11.1\,V--12.6\,V LiPo rail).
    \item \textbf{Output Voltage \& Current:} Fixed 5.0\,V $\pm 1\%$, up to 3.0\,A continuous (short bursts up to 4\,A).
    \item \textbf{Efficiency:} $\approx 95\%$ @ 12\,V$\to$5\,V conversion at 1\,A load.
    \item \textbf{Dimensions / Form Factor:} $18\,\text{mm} \times 12\,\text{mm} \times 4.5\,\text{mm}$, mass $<2\,\text{g}$.
\end{itemize}

% --- 3. Power Architecture ---
\section{Power Architecture}

\subsection{Dual Parallel LiPo Configuration}
To satisfy peak dynamic current requirements across 10 active joints and extend operational run-time, two identical Orange 3S 1500\,mAh 30C LiPo batteries are coupled in parallel through a balanced XT60 Y-harness.

\begin{table}[h!]
\centering
\small
\renewcommand{\arraystretch}{1.2}
\begin{tabularx}{\textwidth}{l X}
\toprule
\textbf{Combined System Metric} & \textbf{Calculated Value / Capacity} \\
\midrule
Nominal Voltage & 11.1\,V ($3 \times 3.7\,\text{V}$) \\
Fully Charged Voltage & 12.6\,V ($3 \times 4.2\,\text{V}$) \\
Total Energy Capacity & $3000\,\text{mAh}$ ($33.3\,\text{Wh}$) \\
Continuous Discharge Rating & $30\text{C} \times 2 = 60\text{C Equivalent}$ ($180\,\text{A}$ theoretical continuous) \\
Short-Term Peak Discharge & $270\,\text{A}$ peak ($10\,\text{s}$ burst) \\
Max Expected System Load & $27\,\text{A}$ (10$\times$ 2.7\,A stall worst-case) $\ll$ LiPo capability \\
\bottomrule
\end{tabularx}
\caption{Parallel battery configuration parameters.}
\end{table}

\subsection{Protection, Filtering \& Safety Subsystems}
\begin{enumerate}[leftmargin=1.5em, itemsep=0.3em]
    \item \textbf{Individual Pack Fusing:} A 15\,A mini-blade automotive fuse is installed on the positive lead of \textit{each} individual LiPo pack \textit{before} entering the parallel Y-junction. This prevents catastrophic reverse charging or thermal runaway in the event of an internal cell short in one pack.
    \item \textbf{Master XT60 Loop Key:} A removable heavy-duty XT60 shorting plug acts as a physical master safety disconnect, placed immediately downstream of the combined parallel junction.
    \item \textbf{LiPo Low-Voltage Buzzers:} Each pack maintains its own dedicated JST-XH balance port monitor with loud dual-piezo buzzers calibrated to sound at $\le 3.4\,\text{V}/\text{cell}$.
    \item \textbf{Transient Absorption Capacitor:} A 1000\,\textmu F / 25\,V low-ESR electrolytic capacitor is mounted directly across the 12\,V screw terminals of the Bus Servo Adapter (A) to buffer regenerative inductive kickback and dampen switching transients during rapid servo reversals.
    \item \textbf{Logic Power Isolation:} The ESP32 and sensitive sensors receive clean 5.0\,V via the Mini560 buck regulator, completely isolating MCU digital logic from motor voltage sag.
\end{enumerate}

% --- 4. Wiring Details ---
\section{Wiring Details --- On the Robot}

\subsection{12\,V Main Power Distribution Bus}
\begin{itemize}[leftmargin=1.5em, itemsep=0.25em]
    \item \textbf{LiPo Pack \#1 (+)} $\longrightarrow$ 15\,A Fuse \#1 $\longrightarrow$ Y-Harness Branch 1 (+)
    \item \textbf{LiPo Pack \#2 (+)} $\longrightarrow$ 15\,A Fuse \#2 $\longrightarrow$ Y-Harness Branch 2 (+)
    \item \textbf{Combined Positive} $\longrightarrow$ XT60 Loop Key (Master Switch) $\longrightarrow$ Main +12\,V Rail
    \item \textbf{Main +12\,V Rail} branches directly into:
    \begin{enumerate}[leftmargin=1.2em, itemsep=0.1em]
        \item Bus Servo Adapter (A) Screw Terminal \texttt{VIN} (+)
        \item Mini560-5V Buck Converter Input \texttt{IN+}
        \item 1000\,\textmu F 25\,V Capacitor Anode (+)
    \end{enumerate}
\end{itemize}

\subsection{System Ground (GND) Topology}
All grounds are tied in a single-point star ground node at the battery negative junction:
\begin{itemize}[leftmargin=1.5em, itemsep=0.2em]
    \item LiPo Pack \#1 ($-$) and LiPo Pack \#2 ($-$) $\longrightarrow$ XT60 Y-Harness Negative Node.
    \item Common GND connects to Bus Servo Adapter \texttt{GND} terminal, 1000\,\textmu F Capacitor Cathode ($-$), and Mini560 \texttt{IN-}.
    \item Mini560 \texttt{OUT-} connects to ESP32 \texttt{GND} pin, establishing unified signal and power reference.
\end{itemize}

\subsection{UART \& Servo Bus Routing}
\begin{table}[h!]
\centering
\small
\renewcommand{\arraystretch}{1.2}
\begin{tabular}{lll}
\toprule
\textbf{ESP32 Pin} & \textbf{Bus Servo Adapter Pin} & \textbf{Function} \\
\midrule
\texttt{GPIO17} (\texttt{UART2\_TX}) & \texttt{RX} & Serial Commands from ESP32 to Bus \\
\texttt{GPIO16} (\texttt{UART2\_RX}) & \texttt{TX} & Telemetry Feedback from Servos to ESP32 \\
\texttt{5V} & \texttt{5V} & Logic Level Reference \\
\texttt{GND} & \texttt{GND} & Common Signal Ground \\
\bottomrule
\end{tabular}
\caption{ESP32 to Waveshare Bus Servo Adapter pin connections.}
\end{table}

\noindent \textbf{Servo Daisy-Chain Path:}
$$\text{Adapter 3-Pin Port} \xrightarrow{\text{Cable 1}} \text{Servo \#1} \xrightarrow{\text{Cable 2}} \text{Servo \#2} \longrightarrow \cdots \longrightarrow \text{Servo \#9} \xrightarrow{\text{Cable 10}} \text{Servo \#10}$$
The output port of Servo \#10 is left open (or protected with an insulated dummy dust plug).

% --- 5. Base Station Architecture ---
\section{Wiring Details --- Base Station}

\begin{figure}[h!]
\centering
\begin{specbox}{Base Station Architecture}
\begin{itemize}[leftmargin=1.2em, itemsep=0.25em]
    \item \textbf{Raspberry Pi 5 (8GB):} Powered via official 27\,W (5.1\,V, 5\,A) USB-C power supply. Runs Linux (Ubuntu 24.04 / Raspberry Pi OS), ROS 2 communication nodes, Web GUI dashboard, and inverse kinematics solvers.
    \item \textbf{ESP32 Dev Board \#2 (Radio Gateway):} Connected directly to a USB 3.0 port on the Raspberry Pi 5. Powered via 5\,V USB VBUS; enumerates as \texttt{/dev/ttyUSB0} or \texttt{/dev/ttyACM0} @ 115200 or 921600\,baud.
    \item \textbf{Communication Pipeline:}
    $$\text{ESP32 \#1 (Robot)} \underset{<10\,\text{ms}}{\overset{\text{ESP-NOW (2.4\,GHz)}}{\rightleftharpoons}} \text{ESP32 \#2 (Bridge)} \underset{1\,\text{Mbps}}{\overset{\text{USB Serial}}{\rightleftharpoons}} \text{Raspberry Pi 5}$$
\end{itemize}
\end{specbox}
\end{figure}

% --- 6. First Power-Up Sequence ---
\section{First Power-Up Sequence}

\begin{alertbox}{Mandatory Safety Warning}
Execute Steps 1--3 \textbf{strictly} prior to attaching any servo or logic processor. Do not insert the XT60 loop key until all resistance checks confirm no ground-to-power shorts exist.
\end{alertbox}

\begin{description}[leftmargin=1.5em, itemsep=0.6em]
    \item[\textbf{Step 1: Pre-Assembly Visual Inspection (15 min)}]
    \begin{itemize}[leftmargin=1.2em, itemsep=0.15em]
        \item Confirm 15\,A blade fuses are seated in both positive harness branches.
        \item Verify the XT60 Loop Key is removed (system in open circuit).
        \item Inspect LiPo packs for swelling or mechanical punctures; verify cell voltages on buzzer alarms ($\ge 3.8\,\text{V}/\text{cell}$).
        \item Check capacitor polarity: stripe / negative lead to \texttt{GND}, positive lead to \texttt{+12V}.
    \end{itemize}

    \item[\textbf{Step 2: Megohm Continuity \& Short-Circuit Test (10 min)}]
    \begin{itemize}[leftmargin=1.2em, itemsep=0.15em]
        \item Disconnect ESP32 from the 5\,V buck regulator.
        \item Set digital multimeter to Resistance / Megohm range ($\text{M}\Omega$).
        \item Measure resistance across the main 12\,V rail and GND rail. Resistance must register $> 10\,\text{M}\Omega$ (charging capacitor may show transient low reading before settling at high $\text{M}\Omega$).
        \item If reading is $< 1\,\text{M}\Omega$, halt immediately and inspect wiring harnesses for solder bridges.
    \end{itemize}

    \item[\textbf{Step 3: Initial Power-ON with Voltage Verification (20 min)}]
    \begin{itemize}[leftmargin=1.2em, itemsep=0.15em]
        \item Insert the XT60 Loop Key. No spark, popping, or smoke should occur.
        \item Measure voltage at the Bus Servo Adapter screw terminal: must read $11.1\,\text{V} - 12.6\,\text{V}$.
        \item Measure voltage across Mini560 output terminals: must read $5.0\,\text{V} \pm 0.1\,\text{V}$.
        \item Disconnect Loop Key before proceeding.
    \end{itemize}

    \item[\textbf{Step 4: Single-Servo Daisy-Chain Staging (15 min)}]
    \begin{itemize}[leftmargin=1.2em, itemsep=0.15em]
        \item Connect only Servo \#1 to the adapter bus output port. Insert Loop Key.
        \item Confirm the servo LED indicators blink or steady-state illuminate. Verify the servo body remains at ambient temperature.
        \item Incrementally attach Servos \#2 through \#10 one by one, checking thermal state at each step.
    \end{itemize}

    \item[\textbf{Step 5: Load ESP32 Test Firmware (10 min)}]
    \begin{itemize}[leftmargin=1.2em, itemsep=0.15em]
        \item Flash the servo ID read-back firmware to ESP32 \#1 via USB.
        \item Verify bidirectional half-duplex UART ping responses across the 1\,Mbps serial bus.
    \end{itemize}

    \item[\textbf{Step 6: ESP-NOW Wireless Pairing (10 min)}]
    \begin{itemize}[leftmargin=1.2em, itemsep=0.15em]
        \item Flash the receiver firmware to ESP32 \#2 (connected to base station) and monitor serial output at 115200\,baud.
        \item Power up ESP32 \#1 on the robot; verify real-time packet stream reception with $<15\,\text{ms}$ interval.
    \end{itemize}
\end{description}

% --- 7. Servo Integration & ID Assignment ---
\section{Servo Integration \& ID Assignment}
All Waveshare ST3215 servos are pre-programmed from the factory with a default ID of \textbf{1}. To prevent bus collisions, each servo must be individually programmed with a unique identifier ($\text{ID} \in [1, 10]$) prior to final mechanical assembly.

\subsection{Sequential ID Assignment Procedure}
\begin{enumerate}[leftmargin=1.5em, itemsep=0.2em]
    \item Disconnect all servos from the bus adapter.
    \item Connect \textbf{only one} target servo to the adapter port.
    \item Flash and run the ID Assignment sketch on ESP32 \#1.
    \item Input the desired target ID (1--10) via the Serial Monitor.
    \item The sketch writes the new ID into the servo's non-volatile EEPROM register (Register \texttt{0x05}) and executes an EEPROM lock.
    \item Unplug the programmed servo, label it physically (e.g., Joint 1 to Joint 10), and repeat for the remaining units.
\end{enumerate}

\subsection{ID Assignment Source Code}
\begin{lstlisting}[language=C++, caption={ESP32 Arduino Sketch for ST3215 Servo ID Assignment.}]
#include <Arduino.h>
#include <HardwareSerial.h>

// ESP32 UART2 (GPIO16=RX, GPIO17=TX)
HardwareSerial ServoSerial(2);

void setServoID(uint8_t currentID, uint8_t newID) {
    // Feetech SCServo Protocol Packet:
    // [0xFF, 0xFF, ID, LENGTH, INSTRUCTION, PARAM_REG, VALUE, CHECKSUM]
    uint8_t cmd[7];
    cmd[0] = 0xFF;              // Header 1
    cmd[1] = 0xFF;              // Header 2
    cmd[2] = currentID;         // Current ID (Default = 1)
    cmd[3] = 0x04;              // Packet Length (Cmd + Reg + Value + Checksum)
    cmd[4] = 0x03;              // Instruction: WRITE_DATA (0x03)
    cmd[5] = 0x05;              // Register Address: ID register (0x05)
    cmd[6] = newID;             // Value: New Target ID
    
    // Compute Checksum: ~(ID + LENGTH + INSTRUCTION + PARAM_REG + VALUE) & 0xFF
    uint8_t sum = cmd[2] + cmd[3] + cmd[4] + cmd[5] + cmd[6];
    uint8_t checksum = ~sum;

    uint8_t packet[8];
    memcpy(packet, cmd, 7);
    packet[7] = checksum;

    // Transmit packet at 1 Mbps
    ServoSerial.write(packet, 8);
    ServoSerial.flush();

    Serial.printf("Transmitted ID change request: %d -> %d (Checksum: 0x%02X)\n", 
                  currentID, newID, checksum);
}

void setup() {
    Serial.begin(115200);
    ServoSerial.begin(1000000, SERIAL_8N1, 16, 17); // 1 Mbps, RX=16, TX=17
    delay(1000);
    Serial.println("\n=== ST3215 Servo ID Programming Tool ===");
    Serial.println("Enter target ID (1 - 10) in the Serial Monitor:");
}

void loop() {
    if (Serial.available() > 0) {
        int inputVal = Serial.parseInt();
        if (inputVal >= 1 && inputVal <= 10) {
            Serial.printf("Assigning target ID: %d ...\n", inputVal);
            setServoID(1, (uint8_t)inputVal);
            delay(500);
            Serial.println("Programming complete. Power cycle servo to verify.");
        } else if (inputVal != 0) {
            Serial.println("Error: Valid ID range is 1 to 10.");
        }
    }
}
\end{lstlisting}

% --- 8. Sensor Integration ---
\section{Sensor Integration}

\subsection{MPU6050 6-Axis IMU (Orientation Feedback)}
Mounted in the head/lead segment of the snake robot to estimate pitch, roll, and lateral acceleration for terrain-adaptive gait modulation.
\begin{itemize}[leftmargin=1.5em, itemsep=0.2em]
    \item \textbf{Module:} GY-521 Breakout Board (with onboard 3.3\,V LDO regulator).
    \item \textbf{Interface:} $\text{I}^2\text{C}$ Standard/Fast Mode (400\,kHz), default 7-bit address \texttt{0x68} (AD0 pin pulled low).
    \item \textbf{Pin Mapping:} \texttt{VCC} $\to$ ESP32 3.3\,V, \texttt{GND} $\to$ ESP32 GND, \texttt{SCL} $\to$ \texttt{GPIO22}, \texttt{SDA} $\to$ \texttt{GPIO21}.
\end{itemize}

\subsection{HC-SR04P Ultrasonic Sensor (Obstacle Detection)}
\begin{alertbox}{Hardware Compatibility Requirement}
Ensure the \textbf{HC-SR04P} (wide voltage 3.0\,V--5.5\,V) module is utilized. Standard HC-SR04 modules output 5\,V logic on the \texttt{ECHO} pin, which will cause permanent over-voltage damage to the ESP32 input stage ($3.3\,\text{V}$ max tolerance).
\end{alertbox}

\begin{itemize}[leftmargin=1.5em, itemsep=0.2em]
    \item \textbf{Pin Mapping:} \texttt{VCC} $\to$ ESP32 3.3\,V (or 5\,V), \texttt{GND} $\to$ ESP32 GND, \texttt{TRIG} $\to$ \texttt{GPIO26} (Output), \texttt{ECHO} $\to$ \texttt{GPIO27} (Input).
\end{itemize}

\subsection{Unified Sensor Polling Code}
\begin{lstlisting}[language=C++, caption={Sensor Integration Sketch for ESP32 Onboard.}]
#include <Wire.h>
#include <Adafruit_MPU6050.h>
#include <Adafruit_Sensor.h>

Adafruit_MPU6050 mpu;
const int TRIG_PIN = 26;
const int ECHO_PIN = 27;

void setup() {
    Serial.begin(115200);
    Wire.begin(21, 22); // SDA=21, SCL=22

    if (!mpu.begin()) {
        Serial.println("Failed to find MPU6050 chip!");
        while (1) { delay(10); }
    }
    mpu.setAccelerometerRange(MPU6050_RANGE_4_G);
    mpu.setGyroRange(MPU6050_RANGE_500_DEG);
    mpu.setFilterBandwidth(MPU6050_BAND_21_HZ);

    pinMode(TRIG_PIN, OUTPUT);
    pinMode(ECHO_PIN, INPUT);
    Serial.println("Sensors initialized successfully.");
}

void loop() {
    // 1. Read IMU
    sensors_event_t a, g, temp;
    mpu.getEvent(&a, &g, &temp);

    // 2. Read Ultrasonic Distance
    digitalWrite(TRIG_PIN, LOW);
    delayMicroseconds(2);
    digitalWrite(TRIG_PIN, HIGH);
    delayMicroseconds(10);
    digitalWrite(TRIG_PIN, LOW);

    long duration = pulseIn(ECHO_PIN, HIGH, 30000); // 30ms timeout
    float distance_cm = (duration == 0) ? -1.0 : (duration / 2.0) / 29.1;

    // Output Telemetry
    Serial.printf("IMU Accel: [%.2f, %.2f, %.2f] m/s^2 | Dist: %.1f cm\n",
                  a.acceleration.x, a.acceleration.y, a.acceleration.z, distance_cm);
    delay(50);
}
\end{lstlisting}

% --- 9. ESP-NOW Wireless Link ---
\section{ESP-NOW Wireless Telemetry \& Command Link}
ESP-NOW is a connectionless, peer-to-peer MAC-layer protocol developed by Espressif, operating on the 2.4\,GHz ISM band.
\begin{itemize}[leftmargin=1.5em, itemsep=0.2em]
    \item \textbf{Packet Payload:} Up to 250 bytes per frame.
    \item \textbf{Latency:} $< 10\,\text{ms}$ deterministic round-trip time.
    \item \textbf{Throughput:} 50\,Hz bidirectional telemetry and gait parameter updates.
\end{itemize}

\subsection{Phase 1: MAC Address Discovery}
Run the following helper code on both boards to determine their factory Wi-Fi MAC addresses:
\begin{lstlisting}[language=C++, caption={ESP32 MAC Address Extraction Script.}]
#include <WiFi.h>
#include <esp_wifi.h>

void setup() {
    Serial.begin(115200);
    WiFi.mode(WIFI_MODE_STA);
    delay(100);
    uint8_t mac[6];
    esp_wifi_get_mac(WIFI_IF_STA, mac);
    Serial.printf("Device Station MAC: %02X:%02X:%02X:%02X:%02X:%02X\n",
                  mac[0], mac[1], mac[2], mac[3], mac[4], mac[5]);
}

void loop() {}
\end{lstlisting}

\subsection{Phase 2: Robot Transmitter Firmware (ESP32 \#1)}
\begin{lstlisting}[language=C++, caption={Transmitter Firmware running on Onboard Robot ESP32.}]
#include <esp_now.h>
#include <WiFi.h>

// Replace with actual Base Station ESP32 #2 MAC address
uint8_t baseStationMAC[] = {0xAA, 0xBB, 0xCC, 0xDD, 0xEE, 0xFF};

typedef struct __attribute__((packed)) {
    float roll;
    float pitch;
    float yaw;
    float head_distance_cm;
    uint16_t servo_current_mA[10];
    uint16_t servo_positions[10];
    uint8_t battery_voltage_deciV; // e.g. 118 = 11.8V
} RobotTelemetryPacket;

RobotTelemetryPacket txData;

void onDataSent(const uint8_t *mac_addr, esp_now_send_status_t status) {
    // Optional delivery acknowledgment logging
}

void setup() {
    Serial.begin(115200);
    WiFi.mode(WIFI_MODE_STA);

    if (esp_now_init() != ESP_OK) {
        Serial.println("Error initializing ESP-NOW");
        return;
    }

    esp_now_register_send_cb(onDataSent);

    esp_now_peer_info_t peerInfo = {};
    memcpy(peerInfo.peer_addr, baseStationMAC, 6);
    peerInfo.channel = 1;
    peerInfo.encrypt = false;

    if (esp_now_add_peer(&peerInfo) != ESP_OK) {
        Serial.println("Failed to add Base Station peer");
    }
}

void loop() {
    // Populate sample telemetry from sensors and ST3215 feedback
    txData.roll = 3.25;
    txData.pitch = -1.10;
    txData.head_distance_cm = 42.5;
    txData.battery_voltage_deciV = 121; // 12.1V

    esp_err_t result = esp_now_send(baseStationMAC, (uint8_t *)&txData, sizeof(txData));
    delay(20); // 50 Hz transmission cycle
}
\end{lstlisting}

\subsection{Phase 3: Base Station Receiver Firmware (ESP32 \#2)}
\begin{lstlisting}[language=C++, caption={Receiver Bridge Firmware on Base Station ESP32.}]
#include <esp_now.h>
#include <WiFi.h>

typedef struct __attribute__((packed)) {
    float roll;
    float pitch;
    float yaw;
    float head_distance_cm;
    uint16_t servo_current_mA[10];
    uint16_t servo_positions[10];
    uint8_t battery_voltage_deciV;
} RobotTelemetryPacket;

RobotTelemetryPacket rxData;

void onDataRecv(const esp_now_recv_info_t *info, const uint8_t *incomingData, int len) {
    if (len == sizeof(RobotTelemetryPacket)) {
        memcpy(&rxData, incomingData, sizeof(RobotTelemetryPacket));
        
        // Forward structured telemetry over high-speed USB-UART to Raspberry Pi 5
        Serial.printf("TELEMETRY,%.2f,%.2f,%.1f,%d\n",
                      rxData.roll, rxData.pitch, rxData.head_distance_cm, 
                      rxData.battery_voltage_deciV);
    }
}

void setup() {
    Serial.begin(115200);
    WiFi.mode(WIFI_MODE_STA);

    if (esp_now_init() != ESP_OK) {
        Serial.println("ESP-NOW Init Failed");
        return;
    }

    esp_now_register_recv_cb(onDataRecv);
    Serial.println("ESP-NOW Base Station Receiver Online. Awaiting packets...");
}

void loop() {
    // Receiver loop operates asynchronously via hardware interrupt callbacks
    delay(10);
}
\end{lstlisting}

% --- Summary & Status ---
\section{Project Status \& Next Milestones}
\begin{specbox}{Document Summary \& Status}
\begin{itemize}[leftmargin=1.2em, itemsep=0.3em]
    \item \textbf{Status:} Phase 2 (Electrical Redesign, Component Selection, Safety Architecture) is \textbf{Complete}.
    \item \textbf{Readiness:} Phase 3 (Harness Fabrication, 3D Print Integration, Subsystem Bench Testing) is ready to commence.
    \item \textbf{Next Review Milestone:} After physical arrival of Waveshare ST3215 motors, adapter board, and completion of the first 2-segment mechanical articulated joint test bench.
\end{itemize}
\end{specbox}

\end{document}

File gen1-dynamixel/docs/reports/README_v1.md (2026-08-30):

# 🐍 SURGE-090: Self-Adaptive Smart Snake Robot

A bio-inspired, autonomous snake robot built on **Raspberry Pi** and **ROBOTIS Dynamixel XL330** servo motors. SURGE-090 uses a sinusoidal lateral undulation gait to slither forward and detects obstacles using only motor current feedback — no external sensors required.

---

## 📽️ Demo

> Hardware test footage is available in the project working folder.

---

## ✨ Key Features

- **10-DOF Serpentine Locomotion** — Sinusoidal lateral undulation gait implemented in pure Python
- **Sensorless Obstacle Detection** — Monitors motor current draw; a current spike (> 350 mA) signals a collision
- **Autonomous Evasion State Machine** — Automatically reverses for 2.5 s → turns for 4 s → resumes forward slither
- **Dual Operation Modes** — Tethered (via laptop USB) or fully untethered (on-board Raspberry Pi)
- **3D-Printed Body Segments** — SolidWorks + STEP + STL files included for all structural parts

---

## 🏗️ System Architecture

```
┌───────────────────────────────────────┐
│           Raspberry Pi 5              │
│                                       │
│  main.py  (Control Loop @ 50 Hz)      │
│    │                                  │
│    ├─► obstacle_avoidance.py          │
│    │     State Machine:               │
│    │     SLITHER → SLITHER_REV        │
│    │              → SLITHER_TURN      │
│    │              → SLITHER           │
│    │                                  │
│    ├─► snake_locomotion.py            │
│    │     Sinusoidal gait generation   │
│    │                                  │
│    └─► servo_driver.py               │
│          Dynamixel SDK calls          │
└──────────────┬────────────────────────┘
               │ USB (Micro-USB)
        ┌──────▼──────┐
        │  ROBOTIS U2D2│ ← USB-to-TTL adapter
        │  + PHB Board │ ← 5V power injection
        └──────┬───────┘
               │ X3P TTL cables (daisy chain)
    ┌──────────▼──────────────────────────┐
    │  Motor 1 ─── Motor 2 ─── ... ─── Motor 10  │
    │     Dynamixel XL330-M288-T          │
    └─────────────────────────────────────┘
```

---

## 📁 Repository Structure

```
git/
├── main.py                     # Entry point: control loop
├── servo_test.py               # Standalone servo testing script
├── requirements.txt            # Python dependencies
├── install_requirements.cmd    # Windows one-click dependency installer
├── hardware_bom.md             # Bill of Materials with costs (budget: ₹1,00,000)
├── starter_kit_manual.md       # Getting started with a single motor
├── SSH_LOGIN_INSTRUCTIONS.md   # How to SSH into the Raspberry Pi
├── Component_flow.png          # System architecture diagram
│
├── src/                        # Core robot logic (Python modules)
│   ├── snake_locomotion.py     # Sinusoidal gait & position calculator
│   ├── kinematics.py           # Joint angle kinematics
│   ├── servo_driver.py         # Low-level Dynamixel SDK wrapper
│   ├── obstacle_avoidance.py   # Current-based collision state machine
│   ├── torque_controller.py    # Torque limits & safety management
│   └── robot_config.py         # Centralized hardware constants
│
├── tests/                      # Hardware validation scripts
│   ├── test_dynamixel_ping.py  # Ping all motors to verify connectivity
│   └── test_motor_feedback.py  # Live motor position, velocity & current readout
│
├── 3d_parts/                   # CAD files for 3D-printed body
│   ├── segment1.SLDPRT / .STEP / .STL
│   ├── segement2.SLDPRT / .STEP / .STL
│   ├── XL,XC-330.stp           # Dynamixel motor reference model
│   └── assembly.SLDASM         # Full robot assembly
│
└── instruction/                # Setup & reference documentation
    ├── raspberry_pi_setup_guide.md
    ├── wiring_diagram.md
    ├── parts_and_safety.md
    └── additional_parts_spreadsheet.md
```

---

## 🛒 Hardware Requirements

| Component | Qty | Approx. Cost |
|---|:---:|---|
| Dynamixel XL330-M288-T (+ 2 spares) | 12 | ₹36,000 |
| ROBOTIS U2D2 (USB-to-TTL adapter) | 1 | ₹4,500 |
| U2D2 Power Hub Board (PHB) | 1 | ₹1,500 |
| Raspberry Pi 4/5 (4 GB) | 1 | ₹5,500 |
| 5V / 10–20A Power Supply *(tethered)* | 1 | ₹2,000 |
| *or* 2S LiPo + 5V UBEC *(untethered)* | 1 | ₹3,500 |
| Dynamixel X3P Cables (pack of 10) | 1 | ₹1,500 |
| F623ZZ Flange Bearings | 10 | ₹1,000 |
| Braided Expandable Sleeving ("skin") | 1 m | ₹2,000 |
| M2 / M2.5 Machine Screw Assortment | 1 | ₹500 |
| **Total** | | **~₹52,500 / ₹1,00,000** |

> See [`hardware_bom.md`](hardware_bom.md) for full specifications and sourcing notes.

---

## ⚙️ Software Setup

### Prerequisites

- Python 3.8+
- A Dynamixel-compatible serial port (USB via U2D2)

### 1. Clone the Repository

```bash
git clone <repo-url>
cd surge090
```

### 2. Install Dependencies

**Windows (one-click):**
```cmd
install_requirements.cmd
```

**Any platform:**
```bash
pip install -r requirements.txt
```

Dependencies: `dynamixel-sdk >= 4.0.5`, `pyserial >= 3.5`

### 3. Set Your COM Port

Open [`main.py`](../../main.py) and verify the serial port matches your system:

```python
# Windows
DEVICENAME = 'COM3'

# Linux / Raspberry Pi
DEVICENAME = '/dev/ttyUSB0'
```

Check the correct port in **Device Manager** (Windows) or with `ls /dev/ttyUSB*` (Linux).

### 4. Assign Motor IDs

All factory Dynamixel motors ship with ID `1`. You must assign unique IDs 1–10 **one at a time** before daisy-chaining:

1. Plug in **one motor** at a time to the U2D2 PHB.
2. Open **Dynamixel Wizard 2.0** on your PC.
3. Scan and change the motor's ID (1 through 10).
4. Unplug, plug in the next motor, repeat.

---

## 🚀 Running the Robot

### Quick Hardware Test (single motor)

```bash
python tests/test_motor_feedback.py
```

This enables torque, holds center position, and streams live **Position / Velocity / Current (mA)** to the terminal. Try forcing the horn with your fingers to see the current spike that drives obstacle detection.

### Ping All Motors

```bash
python tests/test_dynamixel_ping.py
```

Verifies that all 10 motors respond on the TTL bus.

### Single Servo Test

```bash
python servo_test.py
```

### Full Robot — Main Control Loop

```bash
python main.py
```

The snake will initialize all motors, then begin the sinusoidal slither gait. Press **Ctrl + C** to halt and safely disable all motor torques.

---

## 🧠 How It Works

### Locomotion — Lateral Undulation

Each odd-numbered motor is a **yaw** joint (lateral bending); each even-numbered motor is a **pitch** joint (held flat). The gait is produced by a travelling sine wave propagated along the motor chain:

```
position[i] = center + A · sin(ω·t − i·φ)
```

| Parameter | Value | Description |
|---|---|---|
| `amplitude` | 400 ticks | Peak deflection from centre |
| `frequency` | 3.0 | Wave propagation speed |
| `phase_shift` | 1.2 rad | Phase offset between adjacent segments |
| `center_pos` | 2048 | Neutral encoder count (0° for XL330) |

### Obstacle Avoidance — State Machine

The robot uses **motor current as a tactile sensor**. No external hardware is needed.

```
SLITHER ──(current > 350 mA)──► SLITHER_REV (2.5 s)
                                      │
                              (timer expires)
                                      ▼
                              SLITHER_TURN (4.0 s)
                                      │
                              (timer expires)
                                      ▼
                                  SLITHER
```

---
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

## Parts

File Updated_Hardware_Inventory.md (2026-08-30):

# Smart Snake Robot — Updated Hardware Inventory

**Date Updated:** 30 August 2026  
**Status:** Phase 3 (Fabrication & Assembly)  
**Generation:** Gen 2 — Waveshare ST3215 (Gen 1 Dynamixel XL330 hardware is gone — see [`gen1-dynamixel/`](gen1-dynamixel/) for historical record)

---

## Current Equipment On Hand

### Motors & Driver
- [x] **10× Waveshare ST3215 servos** (6–12.6V, 1 Mbps half-duplex TTL, 2.7A stall, 30 kg·cm ≈ 2.94 N·m @ 12V)
  - 12-bit magnetic absolute encoder (0–4095, center 2048)
  - Feetech SMS/STS protocol 1, half-duplex
  - **All ship as ID 1** — must assign IDs 1–10 individually before daisy-chaining
  - ID assignment: use `firmware/assign_ids/` (Arduino) or `tools/assign_id.py` (Python via bridge)
- [x] **Waveshare Bus Servo Driver with integrated ESP32**
  - Built-in ESP32 on the driver board
  - Servo UART: **GPIO 18 RX / GPIO 19 TX**, 1 Mbps (if ping is silent, swap pins)
  - UART interface to servo bus
  - Simplifies wiring compared to external adapter + separate MCU
  - ⚠ Input voltage range, onboard 5V logic regulation, and current-monitor availability **not yet verified against Waveshare wiki**

### Microcontrollers
- [x] **ESP32 dev board #1** (on Waveshare servo driver) — runs either `usb_servo_bridge` (bench) or `robot_esp32` (field), mutually exclusive
- [x] **ESP32 dev board #2** (for base station) — runs `base_esp32` firmware, receives ESP-NOW telemetry, forwards to Pi 5 via USB serial @ 115200 baud

### Power Supply
- [x] **Mean Well LRS-100-5** (industrial 5V power supply, 100W, regulated)
  - Output: 5V @ 20A continuous
  - Input: 90–264V AC universal
  - **⚠ Below the ST3215 minimum of 6.0V — CANNOT feed the servo bus directly**
  - Role: Base station / Pi 5 / ESP32 power, or input to XL6009 boost for single-servo bench tests
  
- [x] **1× 3S LiPo 1800mAh battery**
  - Nominal voltage: 11.1V (3.7V × 3 cells)
  - Charged voltage: 12.6V, floor: 9.0V (3.0V per cell)
  - Energy: 20.0 Wh (down from originally planned 33.3 Wh with 2× 1500mAh)
  - Connector type: ⚠ **TBD — verify from pack label (XT60 / XT30 / Deans)**
  - Discharge rating: ⚠ **TBD — verify C rating from pack label** (need ≥15C for 27A worst-case stall)
  - **This is the correct robot power source** — sits directly in the ST3215 6.0–12.6V range, no conversion needed
  - Estimated runtime: ~14 min @ 6A avg, ~22 min @ 4A avg, ~43 min @ 2A avg (80% DoD)

- [x] **XL6009 Boost Converter**
  - Input: 5–32V → Output: adjustable step-up
  - Intended role: **5V Mean Well → 12V bench rail for single-servo ID programming and one-servo tests**
  - ⚠ Commonly quoted "4A" is a switch/input limit — actual output at 12V from 5V input is **~1.5A max** (≈1–2 servos under light load)
  - **Not in the robot power path** — the 3S LiPo feeds servo VIN directly
  - **Not suitable for 10-servo operation** — the Mean Well + XL6009 path peaks at ~18W, 10-servo stall is 324W

### Sensors
- [x] **Raspberry Pi Camera Module 3**
  - 12 MP IMX708, autofocus, **CSI-2 ribbon interface**
  - Wide-angle lens (~160° FOV)
  - **⚠ Requires a Raspberry Pi host** — cannot connect to ESP32 (no SPI/I²C camera path exists)
  - CSI ribbon is short (~30 cm max without extension)
  - Role: base station vision (mounted on Pi 5), or robot-mounted with CSI extension cable (~1m)
  
- [x] **MPU6050 IMU** (orientation & acceleration feedback)
  - I²C interface, default address **0x68**
  - GPIO 21 SDA, GPIO 22 SCL on robot ESP32
  - 6-axis: 3-axis accelerometer + 3-axis gyroscope
  - Code reference: `Config.IMU_I2C_ADDR`, `Config.IMU_SDA_GPIO`, `Config.IMU_SCL_GPIO` in [`gen2-st3215/src/robot_config.py`](gen2-st3215/src/robot_config.py)

### Compute
- [x] **Raspberry Pi 5, 8GB RAM** (base station, not onboard robot)
  - Runs `base_station.py` for ESP-NOW telemetry reception
  - Camera Module 3 host (CSI-2)
  - Telemetry dashboard & control UI
  - ⚠ Needs a dedicated 5V 5A USB-C power supply (not yet acquired)

---

## Firmware Status

All firmware exists in [`gen2-st3215/firmware/`](gen2-st3215/firmware/). Board: **ESP32 Dev Module** in Arduino IDE.

| Sketch | Target | Function | Status |
|---|---|---|---|
| `assign_ids/` | Waveshare driver ESP32 | One-at-a-time servo ID assignment (1–10) | ✅ Written |
| `usb_servo_bridge/` | Waveshare driver ESP32 | USB CDC @ 1 Mbps ↔ servo UART (bench mode for Python) | ✅ Written |
| `robot_esp32/` | Waveshare driver ESP32 | Field: onboard gait CPG + MPU6050 + current stall FSM + ESP-NOW telemetry | ✅ Written |
| `base_esp32/` | ESP32 #2 | ESP-NOW receiver → USB serial @ 115200 to Pi 5 | ✅ Written |

Python bench stack (`main.py`, `src/`) is also complete — Feetech protocol driver, 10-DOF gait, current-stall obstacle detection, mock mode (`SURGE_MOCK=1`).

---

## Items REMOVED from Original Plan

### Power Supply Changes
- ~~2× 3S LiPo 1500mAh 30C packs (parallel configuration)~~ → Replaced with single 3S 1800mAh (direct to servo bus)
- ~~Mini560-5V buck converter (3A)~~ → Mean Well LRS-100-5 serves 5V needs at base station
- ~~2× 15A mini blade fuses~~ → Single pack removes reverse-charge failure mode; still need **1 inline fuse**
- ~~XT60 Y-harness~~ → Not needed with single LiPo
- ~~XT60 loop key (master switch)~~ → **Still needed** — recommend adding for safe disconnect
- ~~2× LiPo low-voltage alarms~~ → **Still needed** — recommend single alarm or BMS module
- ~~iMAX B6 balance charger~~ → **Still needed** for LiPo charging and storage

### Sensors Removed
- ~~HC-SR04P ultrasonic sensor~~ → Replaced with Raspberry Pi Camera Module 3. However, a head-mounted HC-SR04**P** (3.3V-safe) or VL53L0X is still recommended for simple real-time obstacle distance on the ESP32.

### Wiring Components Removed
- ~~1000µF capacitor (transient suppression)~~ → **Still needed** — protects against servo inrush current spikes
- ~~XT60 connectors & pigtails~~ → Connector type TBD pending LiPo verification
- ~~16AWG silicone wire~~ → **Still needed** for power wiring from LiPo → fuse → driver

---

## Power Architecture (Resolved)

### Robot Power (Field Operation)
```
3S LiPo 1800mAh (11.1–12.6V)
    ↓ [XT60/XT30/Deans — verify from pack]
    ↓
[Inline fuse — size TBD] → [XT60 loop key disconnect]
    ↓
[1000µF 25V cap — transient suppression]
    ↓
Waveshare Bus Servo Driver VIN (6.0–12.6V)
    ├→ UART 1 Mbps → 10× ST3215 servos (daisy-chain)
    ├→ Built-in ESP32 (gait CPG + IMU + ESP-NOW)
    └→ MPU6050 IMU (I²C GPIO 21/22)
```

### Bench Power (Single-Servo Testing / ID Programming)
```
Mean Well LRS-100-5 (5V 20A)
    ↓
XL6009 boost (5V → 12V, ~1.5A max output)
    ↓
Waveshare Driver VIN → 1× ST3215 (ID assignment only)
```
> ⚠ This path is rated for **1–2 servos max**. Never attempt 10-servo operation through the XL6009.

### Base Station Power
```
Mean Well LRS-100-5 (5V 20A)
    ↓
Raspberry Pi 5 (via USB-C, needs 5V 5A adapter or custom cable)
    ├→ Camera Module 3 (CSI-2)
    ├→ ESP32 #2 (USB serial @ 115200, ESP-NOW receiver)
    └→ Telemetry dashboard / SSH
```

---

## Next Steps

### Phase 3A: Power Architecture Verification
- [x] Power architecture defined (LiPo → direct to driver VIN, no conversion needed)
- [x] XL6009 role clarified (bench-only, not in robot power path)
- [ ] Verify LiPo connector type and C rating from pack label
- [ ] Acquire: inline fuse, loop key, 1000µF cap, LiPo alarm/BMS, charger
- [ ] Test single-servo bench power via XL6009 before attempting field power

### Phase 3B: Servo Bring-Up
- [ ] Flash `assign_ids` to driver ESP32, assign IDs 1–10 (one servo at a time, powered via XL6009 bench rail)
- [ ] Flash `usb_servo_bridge`, run `python servo_test.py` to verify single-servo position control
- [ ] Run `python tests/test_st3215_ping.py` to verify bus connectivity
- [ ] Run `python tests/test_motor_feedback.py` for current monitoring calibration
- [ ] Calibrate `OBSTACLE_CURRENT_THRESHOLD_MA` (currently 1200 mA — measure actual free-run vs stall)

### Phase 3C: Sensor Integration
- [ ] Wire MPU6050 to robot ESP32 (I²C GPIO 21/22)
- [ ] Test IMU readings via firmware
- [ ] Mount Camera Module 3 on Pi 5 (CSI-2), test streaming
- [ ] Decide camera placement: base station fixed vs robot-mounted with extension cable

### Phase 3D: Wireless Communication
- [ ] Flash `robot_esp32` to driver ESP32
- [ ] Flash `base_esp32` to ESP32 #2
- [ ] Test ESP-NOW telemetry link
- [ ] Run `base_station.py` on Pi 5 to verify telemetry reception

### Phase 3E: Mechanical Assembly
- [ ] Print body segments using v4 design (NOT v5 — v5 has dimensional errors, NOT v6 — unverified)
- [ ] Install F623ZZ flange bearings (horn-opposite side)
- [ ] Attach friction pads / TPU feet to belly
- [ ] Assemble full 10-segment chain
- [ ] Route servo daisy-chain cables through body

---

## Risk & Gap Analysis

| Component | Status | Issue | Priority |
|---|---|---|---|
| Protection circuits | ⚠ Missing | No fuse, no BMS, no loop key — LiPo safety critical | **CRITICAL** |
| LiPo specs | ⚠ Unverified | Connector type and C-rating unknown — affects max current | HIGH |
| Waveshare driver specs | ⚠ Unverified | Input voltage range, 5V regulation, current sensing — verify from wiki | HIGH |
| Servo daisy-chain cables | ⚠ Missing | Need 3-pin bus connectors for 10-servo chain | HIGH |
| Body segments | ⚠ Not printed | Need PLA+ prints of v4 design + bearings + fasteners | HIGH |
| Friction pads | ⚠ Missing | Snake cannot locomote without anisotropic belly friction | HIGH |
| Pi 5 power supply | ⚠ Missing | Need 5V 5A USB-C adapter for base station | MEDIUM |
| Distance sensor | ⚠ Missing | HC-SR04P or VL53L0X for head-mounted obstacle detection | MEDIUM |
| LiPo charger | ⚠ Missing | Need iMAX B6 or equivalent for safe charging/storage | MEDIUM |
| Camera extension cable | ⚠ TBD | Only needed if camera mounted on robot body | LOW |

---

## Bill of Materials (Current + Gaps)

### ✓ In Inventory (9 items, ~19 physical units)
| # | Component | Qty | Role |
|:---:|---|:---:|---|
| 1 | Waveshare Bus Servo Driver with ESP32 | 1 | Servo bus master + robot MCU |
| 2 | Waveshare ST3215 servos | 10 | 10-DOF snake joints |
| 3 | ESP32 dev board #2 | 1 | Base station ESP-NOW receiver |
| 4 | Mean Well LRS-100-5 | 1 | 5V bench / base station supply |
| 5 | XL6009 boost converter | 1 | 5V→12V bench rail (1-servo only) |
| 6 | 3S LiPo 1800mAh | 1 | Robot field power (direct to VIN) |
| 7 | Raspberry Pi 5 (8GB) | 1 | Base station compute |
| 8 | Raspberry Pi Camera Module 3 | 1 | Vision (CSI-2 on Pi 5) |
| 9 | MPU6050 IMU | 1 | Robot orientation sensing |

### ⚠ Missing / Needs Procurement (~₹10,000 estimated)
| # | Component | Qty | Est. Cost (₹) | Priority |
|:---:|---|:---:|:---:|:---:|
| 10 | Inline fuse + holder | 1 | 200 | CRITICAL |
| 11 | LiPo alarm / BMS module | 1 | 300 | CRITICAL |
| 12 | XT60 loop key (power disconnect) | 1 | 200 | CRITICAL |
| 13 | 3S LiPo balance charger (iMAX B6) | 1 | 2,500 | HIGH |
| 14 | LiPo-safe storage bag | 1 | 400 | HIGH |
| 15 | XT60/XT30 connectors + pigtails | 2 | 200 | HIGH |
| 16 | 16–18 AWG silicone wire + heat-shrink | 2m | 500 | HIGH |
| 17 | Servo daisy-chain cables (3-pin TTL) | 12 | 500 | HIGH |
| 18 | PLA+ filament (or pre-printed v4 segments) | 10 | 1,500 | HIGH |
| 19 | F623ZZ flange bearings | 10 | 1,000 | HIGH |
| 20 | M2 & M2.5 machine screws (assorted) | 1 kit | 500 | HIGH |
| 21 | Friction pads / TPU belly feet | 10 | 500 | HIGH |
| 22 | 1000µF 25V low-ESR capacitor | 1 | 100 | MEDIUM |
| 23 | HC-SR04P or VL53L0X distance sensor | 1 | 300 | MEDIUM |
| 24 | Pi 5 USB-C power supply (5V 5A) | 1 | 1,000 | MEDIUM |
| 25 | CSI ribbon extension cable (~1m) | 1 | 300 | LOW |
| 26 | Heat-shrink tubing assortment | 1 | 200 | LOW |
| | **Estimated Total** | | **~₹10,200** | |

---

## Summary of Changes from Original Plan

| Item | Original | Current | Reason |
|---|---|---|---|
| Servos | Dynamixel XL330-M288-T (5V, 0.52 Nm) | Waveshare ST3215 (12V, 2.94 Nm) | XL330 unobtainable in India; ST3215 is 5.6× stronger |
| Servo driver | Robotis U2D2 + PHB + separate ESP32 | Waveshare Bus Servo Driver (integrated ESP32) | Single board, simpler wiring |
| Power source | 2× 3S 1500mAh parallel (33.3 Wh) | 1× 3S 1800mAh (20.0 Wh) | Simpler; 40% less energy but sufficient |
| Voltage rail | 5V (XL330 limit) | 12V direct from LiPo (ST3215 range) | No buck/boost conversion needed |
| Base station PSU | Mini560-5V buck (3A) | Mean Well LRS-100-5 (5V 20A) | Industrial-grade, overkill but reliable |
| Obstacle sensor | HC-SR04P ultrasonic only | Camera Module 3 + software current stall | Vision-based + proprioceptive stall detection |
| Compute | Raspberry Pi 4 (4GB, onboard robot) | Raspberry Pi 5 (8GB, base station only) | Pi 5 stays off-robot; ESP32 handles onboard control |
| Communication | USB tethered (Pi → U2D2) | ESP-NOW wireless (robot ESP32 ↔ base ESP32 → Pi 5) | Untethered operation |

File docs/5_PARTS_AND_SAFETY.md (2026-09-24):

# SURGE-090 Parts and Safety — Gen 2 (ST3215, split power bus v3)

> **Updated 24 Sep 2026.** What we did before and what we do now is recorded in [What changed](#what-changed) at the end of this file.

Current hardware for the Gen 2 robot. Source of truth for the full BOM and budget:
[`hardware/Updated_Hardware_Inventory.md`](hardware/Updated_Hardware_Inventory.md).
Wiring: [`4_WIRING_DIAGRAM.md`](4_WIRING_DIAGRAM.md). Gen 1 (Dynamixel XL330) parts and safety notes are kept in
[`../gen1-dynamixel/docs/parts_and_safety.md`](../gen1-dynamixel/docs/parts_and_safety.md) — that hardware is no longer in use.

## Parts on hand

| # | Part | Qty | Role |
|:---:|---|:---:|---|
| 1 | Waveshare ST3215 serial bus servo (6–12.6 V, 2.94 N·m, 2.7 A stall @ 12 V) | 10 | Joints ID 1–10 |
| 2 | Waveshare Servo Driver with ESP32 | 1 | Servo bus master + robot MCU (`robot_esp32_v2`) |
| 3 | ESP32 dev board #2 | 1 | Base station ESP-NOW receiver (`base_esp32`) |
| 4 | 3S LiPo 1800 mAh (11.1 V nom, 12.6 V full) | 1 | Robot power |
| 5 | Mean Well LRS-100-5 (5 V 20 A) | 1 | Base station / bench 5 V only |
| 6 | XL6009 boost converter | 1 | 5 V → 12 V bench rail for **one** servo (ID setting) |
| 7 | Raspberry Pi 5, 8 GB | 1 | Base station compute |
| 8 | Raspberry Pi Camera Module 3 (CSI-2) | 1 | Vision on the Pi 5 |
| 9 | MPU6050 IMU | 1 | Orientation, I²C on GPIO 21/22 |

Still to buy (fuses, loop key, inject-board parts, charger, cables, printing, friction pads):
see [`6_ADDITIONAL_PARTS.md`](6_ADDITIONAL_PARTS.md).

---

## ⚡ Safety protocols and voltage limits ⚡

> [!CAUTION]
> **ST3215 servos need 6.0–12.6 V.** Never feed the servo line from the Mean Well 5 V supply or any 5 V rail,
> and never exceed a fully charged 3S pack (12.6 V).

### 1. Servo power (12 V main line)
- Power comes from the 3S LiPo through a **15 A main fuse** and an **XT60 loop key**, then along the main line
  to **5 inject boards**, each with its own **3 A fuse** feeding 2 servos (split bus v3).
- The driver board's servo-port +V wire is **cut**: the board sends only DATA + GND to the servos.
- Walking draw is ~3–5 A total. All 10 servos stalled is ~27 A — the per-group 3 A fuses open first.
- Check polarity at every inject board with a meter before plugging in a servo.

### 2. Controller and logic power
- The Servo Driver is powered from a **buck set to 7.5 V** off the main line. Set and measure the buck **before** connecting the board.
- ESP32 GPIOs are **3.3 V only**. Any head distance sensor must be 3.3 V-safe: use **HC-SR04P** (not HC-SR04) or a VL53L0X.
- Raspberry Pi 5 needs its own **5 V 5 A USB-C** supply. Do not power it from the robot.

### 3. LiPo handling
- Keep the loop key **out** while wiring or working on the robot.
- Charge only with a balance charger (e.g. iMAX B6) in a LiPo-safe bag, never unattended.
- Minimum 3.0 V/cell (9.0 V). Stop using the pack at 3.4 V/cell under load.
- Verify the pack's **connector type and C-rating** from its label (≥ 15C needed for the worst-case load).
- A hardware LiPo alarm or BMS is **still recommended** in addition to the firmware cutoff below.

### 4. Firmware safety (`robot_esp32_v2`)
| Protection | Setting |
|---|---|
| Power-up state | Torque **off** — nothing moves until `RUN` |
| Soft start | One power group at a time, 400 ms apart, then amplitude ramps in over 3 s |
| Joint limit | ±70° (v6 segment mechanical limit is ±80°) |
| Torque limit | 70 % |
| Stall / collision | 1200 mA for 4 consecutive samples → reverse and turn away (calibrate on hardware) |
| Low battery | Stops at 10.2 V (3.4 V/cell) held for 3 s |
| Over-temperature | Stops at 70 °C |
| Emergency | `STOP` → torque off immediately, horns go limp |

### 5. Bring-up rules
- All ST3215s ship as **ID 1**. Set IDs 1–10 **one servo at a time** (`assign_ids` firmware or `tools/assign_id.py`)
  before connecting them in a chain.
- Connect and test one power group at a time (`PING` after each).
- Use `CENTER` when fitting servo horns so every joint is straight.

---

## What changed

### 24 Sep 2026

| Topic | Before | Now | Why |
|---|---|---|---|
| Parts on hand | Pi 4, U2D2 + PHB, 2× XL330, 5 V 10 A supply, ESP32 | 10× ST3215, Servo Driver with ESP32, 2nd ESP32, 3S LiPo, Pi 5, Camera 3, MPU6050 | Moved to Gen 2 hardware |
| Voltage limit | Never exceed 6.0 V (XL330) | Keep servos within 6.0–12.6 V; never feed 5 V | ST3215 range |
| Protection | Software current threshold only | 15 A + 5 × 3 A fuses, loop key, firmware limp boot / soft start / ±70° / 10.2 V / 70 °C stops | LiPo on the robot needs hardware protection |

<details>
<summary>Previous version of this document (before 24 Sep 2026) — Gen 1 Dynamixel</summary>

# SURGE-SNAKE Parts and Safety Protocol

## Parts Ordered (Existing Inventory)
1. **SD card (32GB A1 class 10)** - For Raspberry Pi OS.
2. **Raspberry Pi 4 Model B (4GB RAM)** - Main compute brain.
3. **Power Adapter (USB-C 5V 3A)** - Dedicated power for the Raspberry Pi.
4. **Raspberry Pi Heat Sink (Double Fans)** - Cooling for Pi.
5. **Dynamixel XL330-M288-T (x2)** - Smart servos for the joints (currently 2 for testing).
6. **U2D2 USB Interface** - Translates USB to TTL half-duplex for the Dynamixels.
7. **U2D2 PHB Power Hub Board** - Distributes power and signals to the daisy-chained Dynamixels.
8. **Robot Cable X3P 180mm** - TTL cables to connect motors.
9. **Power Supply (5V 10A - 50W)** - Power source for the Dynamixel network.
10. **ESP32 (38 pin WiFi + Bluetooth)** - Sensor node/secondary controller.

## Missing Parts (To Be Ordered)
Based on the plan for a 10-motor serpentine robot:

1. **Additional Dynamixel XL330-M288-T (x8):** To complete the 10-motor setup (5 pitch, 5 yaw).
2. **Dynamixel X3P Cables (x8):** Need more cables to daisy-chain the new motors.
3. **Mechanical Brackets / Frame:**
   - 3D Printed custom links OR BIOLOID frame components to mechanically connect the motors in alternating Pitch/Yaw configurations.
4. **Friction Pads (CRITICAL):**
   - TPU feet, rubber pads, or passive wheels (that only roll forward/back) attached to the underside of the snake. *Required for Friction Anisotropy so the snake pushes forward instead of wriggling in place.*
5. **Front Obstacle Sensor:** 
   - 1x **HC-SR04** (Ultrasonic) or **VL53L0X** (Time-of-Flight) module to attach to the ESP32 for head-on obstacle detection.
5. **Miscellaneous Wiring:** 
   - Jumper wires to connect ESP32 and sensors.
   - 18 AWG wires to connect the 5V 10A Power Supply to the U2D2 PHB Terminal block.

---

## ⚡ Safety Protocols & Voltage Limits ⚡

> [!CAUTION]
> **CRITICAL: NEVER exceed 6.0V on the Dynamixel XL330 network!**

### 1. Motor Power Line (5V System)
- **Component Limit:** Dynamixel XL330-M288-T operates safely between **3.7V and 6.0V**.
- **Current Setup:** You are using a 5V 10A power supply. This is **PERFECT** and very safe. The U2D2 PHB simply passes the input voltage directly to the motors.
- **Safety Rule:** Ensure the polarity (+ and -) from the 5V power supply to the U2D2 PHB terminal block is correct. Reversing the polarity will permanently damage the U2D2 PHB and the motors.

### 2. Microcontroller Power Limits
- **Raspberry Pi 4:** Must be powered via its official 5V 3A USB-C adapter. Do not back-power it from the U2D2 PHB. Keep the logic connections (USB from Pi to U2D2) isolated from the motor power supply.
- **ESP32:** Can be powered via USB (5V) or via its VIN/VCC pin (5V). Its GPIO pins are **3.3V logic ONLY**. Do not connect a 5V sensor output directly to an ESP32 GPIO pin without a logic level shifter or a voltage divider.

### 3. Untethered / Battery Operation (Future Upgrade)
If you decide to make the snake wireless, you cannot plug a 2S LiPo battery (7.4V - 8.4V) directly into the U2D2 PHB, as it will fry the 6.0V limit XL330 motors.
- **Required Safety Barrier:** You will need a **5V Buck Converter (Step-Down Module)** rated for at least 10 Amps to sit between the LiPo battery and the U2D2 PHB.

### 4. Overcurrent & Stall Safety
The Python code includes software safety limits to prevent motors from burning out if the snake gets stuck on an obstacle:
- We read the `Present_Current` of each Dynamixel. 
- If the current exceeds a set threshold (e.g., indicating a stall or collision), the robot will automatically halt and execute an avoidance maneuver.

</details>

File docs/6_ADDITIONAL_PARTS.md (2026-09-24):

# SURGE-090 Additional Parts — Gen 2 (ST3215, split power bus v3)

> **Updated 24 Sep 2026.** What we did before and what we do now is recorded in [What changed](#what-changed) at the end of this file.

Everything still needed to finish the Gen 2 robot, **excluding the servos, driver, LiPo, Pi 5, camera and IMU**
(already on hand — see [`5_PARTS_AND_SAFETY.md`](5_PARTS_AND_SAFETY.md)).
Prices are the estimates from [`hardware/Updated_Hardware_Inventory.md`](hardware/Updated_Hardware_Inventory.md);
"—" means not yet priced. The Gen 1 (Dynamixel) list is in `gen1-dynamixel/docs/reports/hardware_bom.md`.

## 🔴 Critical — power protection (buy before first power-up)

| Part | Spec | Qty | Est. ₹ |
|---|---|:---:|:---:|
| Main inline fuse + holder | 15 A (mini blade) | 1 | 200 |
| XT60 loop key | Master ON/OFF in the main line | 1 | 200 |
| LiPo alarm or BMS | 3S, low-voltage buzzer | 1 | 300 |

## 🟠 Split bus v3 — inject boards and wiring

| Part | Spec | Qty | Est. ₹ |
|---|---|:---:|:---:|
| Perfboard (small) | One inject board per power group | 5 | — |
| Group fuses | 3 A mini blade + inline holder, **or** 3 A PTC resettable | 5 | — |
| Capacitors | 470 µF 25 V electrolytic, one per inject board | 5 | — |
| 3-pin plug pairs | 5264-style, matching the ST3215 lead | 5 | — |
| Buck converter | Adjustable, set to 7.5 V, feeds the Servo Driver DC jack | 1 | — |
| Main-line wire | 16–18 AWG silicone, red + black, + heat-shrink | 2 m | 500 |
| Tap wire | 20–22 AWG silicone | ~1 m | — |
| XT60/XT30 connectors + pigtails | Match the LiPo connector (verify from label) | 2 | 200 |
| Servo daisy-chain cables | 3-pin TTL, ST3215 compatible | 12 | 500 |
| 1000 µF 25 V low-ESR capacitor | Inrush suppression near the battery (from the original plan) | 1 | 100 |

## 🟡 Charging and storage

| Part | Spec | Qty | Est. ₹ |
|---|---|:---:|:---:|
| Balance charger | iMAX B6 or equivalent, 3S | 1 | 2,500 |
| LiPo-safe bag | Fire-resistant charging/storage bag | 1 | 400 |

## 🟢 Mechanical

| Part | Spec | Qty | Est. ₹ |
|---|---|:---:|:---:|
| PLA+ filament | 1.75 mm, for 10 × v6 segments | 1 kg | 1,500 |
| F623ZZ flange bearings | Horn-opposite side of each joint | 10 | 1,000 |
| M2 / M2.5 machine screws | Assorted kit | 1 | 500 |
| Friction pads or TPU belly feet | **Critical for locomotion** — anisotropic belly friction | 10 | 500 |

## 🔵 Sensors and base station

| Part | Spec | Qty | Est. ₹ |
|---|---|:---:|:---:|
| Head distance sensor | **HC-SR04P** (3.3 V-safe) or VL53L0X — not the 5 V HC-SR04 | 1 | 300 |
| Pi 5 power supply | 5 V 5 A USB-C | 1 | 1,000 |
| CSI camera extension cable | Only if the camera goes on the robot body | 1 | — |

---

### Notes
1. **Fuses vs PTCs:** PTCs are smaller and reset themselves; blade fuses are cheaper and easier to see when blown.
   If fuses trip at power-up, the v2 firmware already soft-starts one group at a time — use 4 A only if it still trips.
2. **Cable tunnel:** check that the Ø8 mm tunnel in each v6 segment fits 2 main-line wires plus the servo lead before buying wire.
3. **Friction pads:** strips of adhesive anti-slip rubber on the belly work; TPU printing is optional.
4. **No logic level shifter needed** if you use the HC-SR04P or VL53L0X.

---

## What changed

### 24 Sep 2026

| Topic | Before | Now | Why |
|---|---|---|---|
| Cables | Dynamixel X3P packs | 3-pin ST3215 cables + split bus v3 inject-board parts | Different servo and power design |
| Battery | Optional 2S LiPo + 5 V 10 A buck | 3S LiPo already on hand; need fuses, loop key, alarm, charger | ST3215 runs on 12 V directly |
| Head sensor | HC-SR04 + logic level shifter | HC-SR04P (3.3 V-safe) or VL53L0X, no shifter | ESP32 pins are 3.3 V only |
| Prices | Retail links | Estimates from the hardware inventory; new v3 parts not yet priced | Keep one source for costs |

<details>
<summary>Previous version of this document (before 24 Sep 2026) — Gen 1 Dynamixel</summary>

# SURGE-SNAKE Additional Parts Spreadsheet

This document outlines everything else you need to complete the SURGE-SNAKE robot, explicitly **excluding the motors**. The items are separated into expensive structural/power upgrades and standard electronic components.

## 🔴 Expensive / Major Components
*These components represent the bulk of the remaining non-motor budget, primarily focusing on the mechanical structure and untethering the robot from the wall.*

| Component Name | Detailed Specifications | QTY | Est. Price (₹) | Trusted Product Link |
| :--- | :--- | :---: | :---: | :--- |
| **Robot Cable-X3P 180mm** | 3-pin JST TTL cables for Dynamixel X-Series. (Usually sold in packs of 10). You need these to daisy chain the remaining 8 joints. | 1 Pack | 2,659 | [MG Super Labs](https://www.mgsuperlabs.co.in/estore/Robot-Cable-X3P-180mm-10pcs) |
| **3D Printer Filament (PLA+)** | 1kg Spool, 1.75mm. Required to 3D print the custom U-brackets that connect the motors in the alternating pitch/yaw format. | 1 | 1,400 | [Robocraze (eSUN PLA+)](https://robocraze.com/products/esun-pla-pro-filament) |

---

## 🟢 Standard Components & Sensors
*These are the cheaper, everyday electronic components required for sensing, wiring, and friction.*

| Component Name | Detailed Specifications | QTY | Est. Price (₹) | Trusted Product Link |
| :--- | :--- | :---: | :---: | :--- |
| **High-Discharge 2S LiPo Battery** | 7.4V, ~2200mAh, 30C+ discharge rate. (Only needed if you want the snake to be completely wireless). | 1 | 1,200 | [Robocraze (Orange LiPo)](https://robocraze.com/collections/lipo-battery) |
| **VL53L0X Laser ToF Sensor** | High-precision Time-of-Flight laser ranging sensor for the head of the snake. Better accuracy than Ultrasonic. | 1 | 450 | [Robocraze (VL53L0X)](https://robocraze.com/products/gy-53-vl53l0x-laser-tof-flight-time-range-sensor-module) |
| **HC-SR04 Ultrasonic Sensor** | *Alternative to VL53L0X.* Cheaper, bulkier acoustic distance sensor. | 1 | 85 | [Robocraze (HC-SR04)](https://robocraze.com/products/ultrasonic-sensor-hc-sr04) |
| **5V 10A DC-DC Buck Converter** | Step-down module. **CRITICAL** if you buy the 7.4V LiPo battery. It drops the 7.4V down to the safe 5.0V needed for the XL330 motors. | 1 | 600 | [ElectronicsComp / Robocraze](https://robocraze.com/collections/step-down-buck-converter) |
| **Logic Level Shifter** | 4-channel bi-directional (3.3V to 5V). Protects the ESP32's 3.3V pins if you use a 5V sensor. | 1 | 60 | [Robocraze (Level Shifter)](https://robocraze.com/products/4-channel-iic-i2c-logic-level-converter) |
| **Jumper Wires (M-F & F-F)** | 40-pin ribbon cables (Dupont). Needed to wire the front sensor to the ESP32. | 1 Set | 120 | [Robocraze (Jumper Wires)](https://robocraze.com/products/jumper-wires-male-to-female-40-pcs) |
| **18 AWG Silicone Wire** | 1 Meter Red, 1 Meter Black. Thick wire to connect the 5V 10A Power Supply to the U2D2 PHB Terminal Block safely. | 1 | 150 | [Robocraze (Silicone Wire)](https://robocraze.com) |
| **TPU Filament OR Rubber Pads** | **CRITICAL for Locomotion.** Anti-slip rubber adhesive pads (or 3D printed TPU feet) for the underside of the brackets to provide Friction Anisotropy. | 1 Pack | 200 | [Amazon India (Rubber Pads)](https://www.amazon.in) |

---

### Usage Notes:
1. **Friction Pads:** You can simply buy a sheet of adhesive 3M rubber anti-slip pads from Amazon or a local hardware store and cut them into strips for the belly of the snake. You do not need to 3D print these if you don't have TPU filament.
2. **LiPo Battery:** If you stick to using the tethered 5V 10A power supply you already ordered, you can completely ignore the LiPo Battery and the 5V Buck Converter.
3. **Cables:** Ensure the Dynamixel cables you buy are exactly **X3P** (JST connectors), as older Bioloid AX-12 cables will not fit the XL330.

</details>

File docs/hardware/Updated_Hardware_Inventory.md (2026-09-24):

# Smart Snake Robot — Updated Hardware Inventory

> **Updated 24 Sep 2026.** What we did before and what we do now is recorded in [What changed](#what-changed) at the end of this file.

**Date Updated:** 24 September 2026 (power design → split bus v3, firmware → `robot_esp32_v2`)  
**Status:** Phase 3 (Fabrication & Assembly)  
**Generation:** Gen 2 — Waveshare ST3215 (Gen 1 Dynamixel XL330 hardware is gone — see [`gen1-dynamixel/`](../../gen1-dynamixel/) for historical record)

---

## Current Equipment On Hand

### Motors & Driver
- [x] **10× Waveshare ST3215 servos** (6–12.6V, 1 Mbps half-duplex TTL, 2.7A stall, 30 kg·cm ≈ 2.94 N·m @ 12V)
  - 12-bit magnetic absolute encoder (0–4095, center 2048)
  - Feetech SMS/STS protocol 1, half-duplex
  - **All ship as ID 1** — must assign IDs 1–10 individually before daisy-chaining
  - ID assignment: use `firmware/assign_ids/` (Arduino) or `tools/assign_id.py` (Python via bridge)
- [x] **Waveshare Bus Servo Driver with integrated ESP32**
  - Built-in ESP32 on the driver board
  - Servo UART: **GPIO 18 RX / GPIO 19 TX**, 1 Mbps (if ping is silent, swap pins)
  - UART interface to servo bus
  - Simplifies wiring compared to external adapter + separate MCU
  - ⚠ Input voltage range, onboard 5V logic regulation, and current-monitor availability **not yet verified against Waveshare wiki**

### Microcontrollers
- [x] **ESP32 dev board #1** (on Waveshare servo driver) — runs either `usb_servo_bridge` (bench) or `robot_esp32_v2` (field), mutually exclusive
- [x] **ESP32 dev board #2** (for base station) — runs `base_esp32` firmware, receives ESP-NOW telemetry, forwards to Pi 5 via USB serial @ 115200 baud

### Power Supply
- [x] **Mean Well LRS-100-5** (industrial 5V power supply, 100W, regulated)
  - Output: 5V @ 20A continuous
  - Input: 90–264V AC universal
  - **⚠ Below the ST3215 minimum of 6.0V — CANNOT feed the servo bus directly**
  - Role: Base station / Pi 5 / ESP32 power, or input to XL6009 boost for single-servo bench tests
  
- [x] **1× 3S LiPo 1800mAh battery**
  - Nominal voltage: 11.1V (3.7V × 3 cells)
  - Charged voltage: 12.6V, floor: 9.0V (3.0V per cell)
  - Energy: 20.0 Wh (down from originally planned 33.3 Wh with 2× 1500mAh)
  - Connector type: ⚠ **TBD — verify from pack label (XT60 / XT30 / Deans)**
  - Discharge rating: ⚠ **TBD — verify C rating from pack label** (need ≥15C for 27A worst-case stall)
  - **This is the correct robot power source** — sits directly in the ST3215 6.0–12.6V range; distributed by **split power bus v3** (see [`power_split_bus_v3.md`](power_split_bus_v3.md))
  - Estimated runtime: ~14 min @ 6A avg, ~22 min @ 4A avg, ~43 min @ 2A avg (80% DoD)

- [x] **XL6009 Boost Converter**
  - Input: 5–32V → Output: adjustable step-up
  - Intended role: **5V Mean Well → 12V bench rail for single-servo ID programming and one-servo tests**
  - ⚠ Commonly quoted "4A" is a switch/input limit — actual output at 12V from 5V input is **~1.5A max** (≈1–2 servos under light load)
  - **Not in the robot power path** — the 3S LiPo feeds the servos through the split bus v3 main line
  - **Not suitable for 10-servo operation** — the Mean Well + XL6009 path peaks at ~18W, 10-servo stall is 324W

### Sensors
- [x] **Raspberry Pi Camera Module 3**
  - 12 MP IMX708, autofocus, **CSI-2 ribbon interface**
  - Wide-angle lens (~160° FOV)
  - **⚠ Requires a Raspberry Pi host** — cannot connect to ESP32 (no SPI/I²C camera path exists)
  - CSI ribbon is short (~30 cm max without extension)
  - Role: base station vision (mounted on Pi 5), or robot-mounted with CSI extension cable (~1m)
  
- [x] **MPU6050 IMU** (orientation & acceleration feedback)
  - I²C interface, default address **0x68**
  - GPIO 21 SDA, GPIO 22 SCL on robot ESP32
  - 6-axis: 3-axis accelerometer + 3-axis gyroscope
  - Code reference: `Config.IMU_I2C_ADDR`, `Config.IMU_SDA_GPIO`, `Config.IMU_SCL_GPIO` in [`gen2-st3215/src/robot_config.py`](../../gen2-st3215/src/robot_config.py)

### Compute
- [x] **Raspberry Pi 5, 8GB RAM** (base station, not onboard robot)
  - Runs `base_station.py` for ESP-NOW telemetry reception
  - Camera Module 3 host (CSI-2)
  - Telemetry dashboard & control UI
  - ⚠ Needs a dedicated 5V 5A USB-C power supply (not yet acquired)

---

## Firmware Status

All firmware exists in [`gen2-st3215/firmware/`](../../gen2-st3215/firmware/). Built with **PlatformIO** from the repo root (`platformio.ini`, board `esp32dev`).

| Sketch | Target | Function | Status |
|---|---|---|---|
| `assign_ids/` | Waveshare driver ESP32 | One-at-a-time servo ID assignment (1–10) | ✅ Written |
| `usb_servo_bridge/` | Waveshare driver ESP32 | USB CDC @ 1 Mbps ↔ servo UART (bench mode for Python) | ✅ Written |
| `robot_esp32_v2/` | Waveshare driver ESP32 | **Field firmware of record:** gait CPG + MPU6050 + stall FSM + ESP-NOW, limp boot, per-group soft start, ±70° limits, 10.2 V / 70 °C stop | ✅ Written |
| `robot_esp32/` | Waveshare driver ESP32 | Superseded by `robot_esp32_v2` | ⚪ Reference only |
| `spin_all/` | Waveshare driver ESP32 | Broadcast sweep smoke test (all servos on factory ID 1) | ✅ Written |
| `base_esp32/` | ESP32 #2 | ESP-NOW receiver → USB serial @ 115200 to Pi 5 | ✅ Written |

Python bench stack (`main.py`, `src/`) is also complete — Feetech protocol driver, 10-DOF gait, current-stall obstacle detection, mock mode (`SURGE_MOCK=1`).

---

## Items REMOVED from Original Plan

### Power Supply Changes
- ~~2× 3S LiPo 1500mAh 30C packs (parallel configuration)~~ → Replaced with single 3S 1800mAh (direct to servo bus)
- ~~Mini560-5V buck converter (3A)~~ → Mean Well LRS-100-5 serves 5V needs at base station
- ~~2× 15A mini blade fuses~~ → Single pack removes reverse-charge failure mode; still need **1 inline fuse**
- ~~XT60 Y-harness~~ → Not needed with single LiPo
- ~~XT60 loop key (master switch)~~ → **Still needed** — recommend adding for safe disconnect
- ~~2× LiPo low-voltage alarms~~ → **Still needed** — recommend single alarm or BMS module
- ~~iMAX B6 balance charger~~ → **Still needed** for LiPo charging and storage

### Sensors Removed
- ~~HC-SR04P ultrasonic sensor~~ → Replaced with Raspberry Pi Camera Module 3. However, a head-mounted HC-SR04**P** (3.3V-safe) or VL53L0X is still recommended for simple real-time obstacle distance on the ESP32.

### Wiring Components Removed
- ~~1000µF capacitor (transient suppression)~~ → **Still needed** — protects against servo inrush current spikes
- ~~XT60 connectors & pigtails~~ → Connector type TBD pending LiPo verification
- ~~16AWG silicone wire~~ → **Still needed** for power wiring from LiPo → fuse → driver

---

## Power Architecture (Resolved)

### Robot Power (Field Operation) — split bus v3
Full design: [`power_split_bus_v3.md`](power_split_bus_v3.md) · wiring: [`../4_WIRING_DIAGRAM.md`](../4_WIRING_DIAGRAM.md)
```
3S LiPo 1800mAh (11.1–12.6V)
    ↓ [XT60/XT30/Deans — verify from pack]
[15 A fuse] → [XT60 loop key]
    ↓
Main line +12 V / GND (16–18 AWG, along the body)
    ├→ 5 inject boards, each: 3 A fuse + 470 µF cap → 2 servos
    │     G1 ID1–2 · G2 ID3–4 · G3 ID5–6 · G4 ID7–8 · G5 ID9–10
    └→ Buck set to 7.5 V → Waveshare Servo Driver DC jack
          ├→ Servo port: DATA + GND only (+V cut) → one UART @ 1 Mbps to ID1…ID10
          ├→ Built-in ESP32 (robot_esp32_v2: gait + IMU + ESP-NOW)
          └→ MPU6050 IMU (I²C GPIO 21/22)
```

### Bench Power (Single-Servo Testing / ID Programming)
```
Mean Well LRS-100-5 (5V 20A)
    ↓
XL6009 boost (5V → 12V, ~1.5A max output)
    ↓
Waveshare Driver VIN → 1× ST3215 (ID assignment only)
```
> ⚠ This path is rated for **1–2 servos max**. Never attempt 10-servo operation through the XL6009.

### Base Station Power
```
Mean Well LRS-100-5 (5V 20A)
    ↓
Raspberry Pi 5 (via USB-C, needs 5V 5A adapter or custom cable)
    ├→ Camera Module 3 (CSI-2)
    ├→ ESP32 #2 (USB serial @ 115200, ESP-NOW receiver)
    └→ Telemetry dashboard / SSH
```

---

## Next Steps

### Phase 3A: Power Architecture Verification
- [x] Power architecture defined — split bus v3 (15 A main fuse, 5 × 3 A group feeds, 7.5 V buck for the driver)
- [x] XL6009 role clarified (bench-only, not in robot power path)
- [ ] Verify LiPo connector type and C rating from pack label
- [ ] Acquire: 15 A fuse, loop key, LiPo alarm/BMS, charger, and the v3 inject-board parts (5 × 3 A fuse, 5 × 470 µF cap, 5 × perfboard, 5 × 3-pin plugs, 7.5 V buck)
- [ ] Test single-servo bench power via XL6009 before attempting field power

### Phase 3B: Servo Bring-Up
- [ ] Flash `assign_ids` to driver ESP32, assign IDs 1–10 (one servo at a time, powered via XL6009 bench rail)
- [ ] Flash `usb_servo_bridge`, run `python servo_test.py` to verify single-servo position control
- [ ] Run `python tests/test_st3215_ping.py` to verify bus connectivity
- [ ] Run `python tests/test_motor_feedback.py` for current monitoring calibration
- [ ] Calibrate `OBSTACLE_CURRENT_THRESHOLD_MA` (currently 1200 mA — measure actual free-run vs stall)

### Phase 3C: Sensor Integration
- [ ] Wire MPU6050 to robot ESP32 (I²C GPIO 21/22)
- [ ] Test IMU readings via firmware
- [ ] Mount Camera Module 3 on Pi 5 (CSI-2), test streaming
- [ ] Decide camera placement: base station fixed vs robot-mounted with extension cable

### Phase 3D: Wireless Communication
- [ ] Flash `robot_esp32_v2` to driver ESP32 (`pio run -e robot_esp32_v2 -t upload`)
- [ ] Flash `base_esp32` to ESP32 #2
- [ ] Test ESP-NOW telemetry link
- [ ] Run `base_station.py` on Pi 5 to verify telemetry reception

### Phase 3E: Mechanical Assembly
- [ ] Print **one v6 test segment** first (v6 is the design of record — see the main README) and check fit + traction; fall back to v4 only if v6 fails. Do NOT use v5 (dimensional errors)
- [ ] Install F623ZZ flange bearings (horn-opposite side)
- [ ] Attach friction pads / TPU feet to belly
- [ ] Assemble full 10-segment chain
- [ ] Route servo daisy-chain cables through body

---

## Risk & Gap Analysis

| Component | Status | Issue | Priority |
|---|---|---|---|
| Protection circuits | ⚠ Missing | No fuse, no BMS, no loop key — LiPo safety critical | **CRITICAL** |
| LiPo specs | ⚠ Unverified | Connector type and C-rating unknown — affects max current | HIGH |
| Waveshare driver specs | ⚠ Unverified | Input voltage range, 5V regulation, current sensing — verify from wiki | HIGH |
| Servo daisy-chain cables | ⚠ Missing | Need 3-pin bus connectors for 10-servo chain | HIGH |
| Body segments | ⚠ Not printed | Need PLA+ prints of v6 design (test one first) + bearings + fasteners | HIGH |
| Friction pads | ⚠ Missing | Snake cannot locomote without anisotropic belly friction | HIGH |
| Pi 5 power supply | ⚠ Missing | Need 5V 5A USB-C adapter for base station | MEDIUM |
| Distance sensor | ⚠ Missing | HC-SR04P or VL53L0X for head-mounted obstacle detection | MEDIUM |
| LiPo charger | ⚠ Missing | Need iMAX B6 or equivalent for safe charging/storage | MEDIUM |
| Camera extension cable | ⚠ TBD | Only needed if camera mounted on robot body | LOW |

---

## Bill of Materials (Current + Gaps)

### ✓ In Inventory (9 items, ~19 physical units)
| # | Component | Qty | Role |
|:---:|---|:---:|---|
| 1 | Waveshare Bus Servo Driver with ESP32 | 1 | Servo bus master + robot MCU |
| 2 | Waveshare ST3215 servos | 10 | 10-DOF snake joints |
| 3 | ESP32 dev board #2 | 1 | Base station ESP-NOW receiver |
| 4 | Mean Well LRS-100-5 | 1 | 5V bench / base station supply |
| 5 | XL6009 boost converter | 1 | 5V→12V bench rail (1-servo only) |
| 6 | 3S LiPo 1800mAh | 1 | Robot field power (via split bus v3) |
| 7 | Raspberry Pi 5 (8GB) | 1 | Base station compute |
| 8 | Raspberry Pi Camera Module 3 | 1 | Vision (CSI-2 on Pi 5) |
| 9 | MPU6050 IMU | 1 | Robot orientation sensing |

### ⚠ Missing / Needs Procurement (~₹10,000 estimated)
| # | Component | Qty | Est. Cost (₹) | Priority |
|:---:|---|:---:|:---:|:---:|
| 10 | Inline fuse + holder (15 A main) | 1 | 200 | CRITICAL |
| 11 | LiPo alarm / BMS module | 1 | 300 | CRITICAL |
| 12 | XT60 loop key (power disconnect) | 1 | 200 | CRITICAL |
| 13 | 3S LiPo balance charger (iMAX B6) | 1 | 2,500 | HIGH |
| 14 | LiPo-safe storage bag | 1 | 400 | HIGH |
| 15 | XT60/XT30 connectors + pigtails | 2 | 200 | HIGH |
| 16 | 16–18 AWG silicone wire + heat-shrink | 2m | 500 | HIGH |
| 17 | Servo daisy-chain cables (3-pin TTL) | 12 | 500 | HIGH |
| 18 | PLA+ filament (or pre-printed v6 segments) | 10 | 1,500 | HIGH |
| 19 | F623ZZ flange bearings | 10 | 1,000 | HIGH |
| 20 | M2 & M2.5 machine screws (assorted) | 1 kit | 500 | HIGH |
| 21 | Friction pads / TPU belly feet | 10 | 500 | HIGH |
| 22 | 1000µF 25V low-ESR capacitor | 1 | 100 | MEDIUM |
| 23 | HC-SR04P or VL53L0X distance sensor | 1 | 300 | MEDIUM |
| 24 | Pi 5 USB-C power supply (5V 5A) | 1 | 1,000 | MEDIUM |
| 25 | CSI ribbon extension cable (~1m) | 1 | 300 | LOW |
| 26 | Heat-shrink tubing assortment | 1 | 200 | LOW |
| 27 | Split bus v3 inject-board parts: 5 × 3 A fuse/PTC, 5 × 470 µF 25 V cap, 5 × perfboard, 5 × 3-pin plug pairs, 20–22 AWG tap wire | 1 set | — (not yet priced) | CRITICAL |
| 28 | Adjustable buck converter set to 7.5 V (driver power) | 1 | — (not yet priced) | HIGH |
| | **Estimated Total** | | **~₹10,200** + items 27–28 | |

---

## Summary of Changes from Original Plan

| Item | Original | Current | Reason |
|---|---|---|---|
| Servos | Dynamixel XL330-M288-T (5V, 0.52 Nm) | Waveshare ST3215 (12V, 2.94 Nm) | XL330 unobtainable in India; ST3215 is 5.6× stronger |
| Servo driver | Robotis U2D2 + PHB + separate ESP32 | Waveshare Bus Servo Driver (integrated ESP32) | Single board, simpler wiring |
| Power source | 2× 3S 1500mAh parallel (33.3 Wh) | 1× 3S 1800mAh (20.0 Wh) | Simpler; 40% less energy but sufficient |
| Voltage rail | 5V (XL330 limit) | 12V from LiPo, split bus v3 (5 fused groups of 2 servos); 7.5 V buck for driver | Per-group fusing; a jam takes out only 2 joints |
| Base station PSU | Mini560-5V buck (3A) | Mean Well LRS-100-5 (5V 20A) | Industrial-grade, overkill but reliable |
| Obstacle sensor | HC-SR04P ultrasonic only | Camera Module 3 + software current stall | Vision-based + proprioceptive stall detection |
| Compute | Raspberry Pi 4 (4GB, onboard robot) | Raspberry Pi 5 (8GB, base station only) | Pi 5 stays off-robot; ESP32 handles onboard control |
| Communication | USB tethered (Pi → U2D2) | ESP-NOW wireless (robot ESP32 ↔ base ESP32 → Pi 5) | Untethered operation |

---

## What changed

### 24 Sep 2026

| Topic | Before | Now | Why |
|---|---|---|---|
| Robot power path | LiPo → inline fuse (size TBD) → loop key → 1000 µF cap → driver VIN → servos | Split bus v3: 15 A fuse → loop key → main line → 5 inject boards (3 A fuse + 470 µF each) → 2 servos per group; 7.5 V buck → driver | Each plug carries only 2 servos' current, a jam takes out only 2 joints, and the voltage drop is almost zero (see `power_split_bus_v3.md`) |
| Field firmware | `robot_esp32` | `robot_esp32_v2` | With 3 A fuses per pair of servos, starting all 10 servos at once could blow fuses; v2 also adds battery/temperature protection |
| Build tool | Arduino IDE (ESP32 Dev Module) | PlatformIO from the repo root (`platformio.ini`) | One environment per sketch |
| Segment to print | v4 (v6 marked unverified) | Print one v6 test segment first; fall back to v4 if it fails | Main README lists v6 as the design of record — **team to confirm** |
| Parts list | No inject-board parts | Items 27–28 added: v3 inject-board parts and 7.5 V buck | Needed for split bus v3 |
| Links | Written relative to repo root (broke after the move) | Fixed to `../../…` | File now lives in `docs/hardware/` |

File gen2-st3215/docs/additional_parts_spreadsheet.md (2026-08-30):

# SURGE-090 — Hardware Inventory (Gen 2 / ST3215)

> **Status:** Physical inventory as of **2026-08-24**. This document replaces the earlier
> XL330-era parts list that previously occupied this file. Everything in §1 is **in hand**.
> None of the Gen 1 Dynamixel hardware remains — see §2.
>
> Where this document and `progress/electrical_system_report.tex` disagree, **this document is
> current**; the report describes a power architecture (2× LiPo, Bus Servo Adapter (A), Mini560)
> that no longer matches the parts on the bench.

---

## 1. In Hand

8 line items, 17 physical units.

| # | Component | Qty | Key Specs | Source of Spec | Cost (₹) |
| :-: | :--- | :-: | :--- | :--- | :--- |
| 1 | **Waveshare Servo Driver with ESP32** | 1 | Bus servo driver board with an **ESP32 module onboard**; drives ST3215 serial bus servos over half-duplex TTL. | ⚠ input voltage range, onboard 5 V logic regulation, and current-monitor availability **not yet verified against the Waveshare wiki** | — |
| 2 | **Waveshare ST3215 serial bus servo** | 10 | 6.0–12.6 V (nominal 11.1–12.0 V); 30 kg·cm ≈ **2.94 N·m @ 12 V**; **2.7 A stall @ 12 V**; 1 Mbps half-duplex TTL; magnetic encoder. Factory default ID = 1 on every unit. | `electrical_system_report.tex` §Servo | — |
| 3 | **ESP32 dev board** (second unit) | 1 | Separate from the ESP32 on the driver board. Available as the ESP-NOW peer, sensor node, or spare. 3.3 V GPIO logic. | — | — |
| 4 | **Mean Well LRS-100-5 SMPS** | 1 | **5 V, 20 A, 100 W** tethered supply. Carried over from the Gen 1 5 V design. **Below the ST3215 6.0 V minimum — cannot feed the servo bus directly.** | Mean Well part number | — |
| 5 | **XL6009 boost converter module** | 1 | Step-**up** DC-DC. Intended role: **5 V LRS-100-5 → 12 V bench rail**. See §3 for the current budget — this path does not scale to 10 servos. | ⚠ continuous output rating **unverified**; the widely-quoted "4 A" is a switch/input limit, not 4 A at the output | — |
| 6 | **LiPo 3S 1800 mAh** | 1 | 11.1 V nominal / 12.6 V charged / 9.0 V floor at 3.0 V per cell. **20.0 Wh**. Directly in the ST3215 range — no conversion needed for the servo rail. | ⚠ C-rating not recorded — confirm from the pack label | — |
| 7 | **Raspberry Pi Camera Module 3** | 1 | 12 MP IMX708, autofocus, **CSI-2 ribbon interface**. | Raspberry Pi product line | — |
| 8 | **MPU6050 IMU** | 1 | 6-axis accel + gyro, I²C, default address **0x68**, 3.3 V-safe. Matches the address the root README already assumes. | Confirmed by you, 2026-08-24 | — |

Cost column left blank deliberately — fill it from actual receipts rather than the estimates
that were in the old version of this file. The ₹1,00,000 SURGE grant reconciliation needs real
numbers, and the previous estimates were never reconciled against spend.

---
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

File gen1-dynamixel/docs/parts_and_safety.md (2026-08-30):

# SURGE-SNAKE Parts and Safety Protocol (Gen 1 / Dynamixel — HISTORICAL)

> [!IMPORTANT]
> **This document is a historical record of the Gen 1 XL330 build. It is not an inventory and not
> a safety protocol for the current robot.**
>
> - **None of the hardware listed below is still held** (confirmed 2026-08-24). The XL330 motors,
>   U2D2, PHB, X3P cables, and Raspberry Pi 4 are gone.
> - **The 6.0 V limit stated further down applies to the XL330 only.** The current Gen 2 robot runs
>   a **12 V** rail with ST3215 servos (6.0–12.6 V). Applying the 6 V rule to Gen 2 hardware is
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

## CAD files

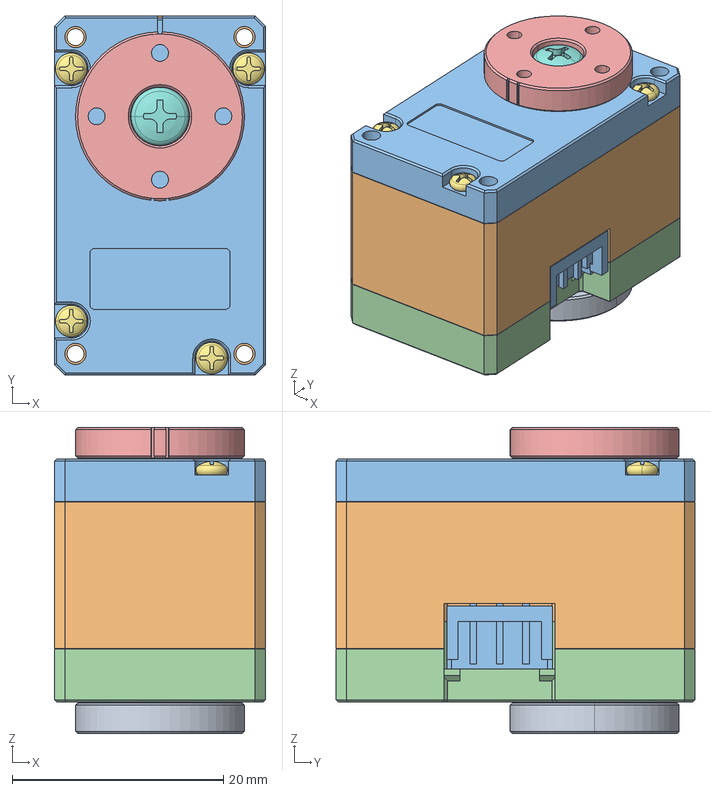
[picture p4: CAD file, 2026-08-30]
gen1-dynamixel/cad/motor-ref/XL,XC-330.stp
20.0 x 34.0 x 29.0 mm
DC15_A01_CASE_M_DUMMY
DC15_A01_CASE_F_DUMMY
DC15_A01_CASE_B_DUMMY
DC15_A01_HORN_DUMMY
DC15_A01_LED_CAP2_DUMMY
PHS_1_7X20_5_DC10 x 4
BTS2_M2_6X8 x 2
DC15_A01_HORN_IDLE2_DUMMY
DC15_A01_IDLE_CAP_DUMMY
B3B-EH x 2

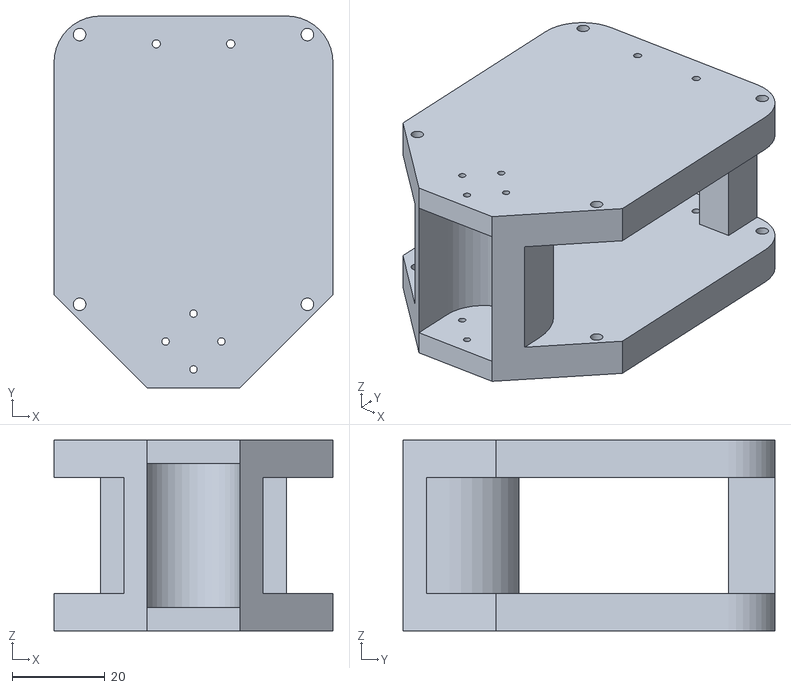
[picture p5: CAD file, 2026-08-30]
gen1-dynamixel/cad/segments/segment1_v1.stl
60.0 x 80.0 x 41.0

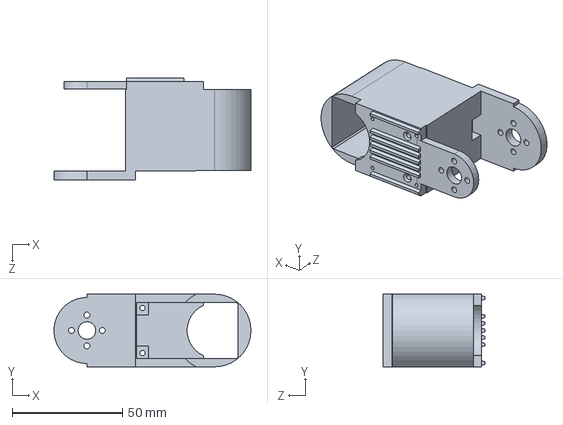
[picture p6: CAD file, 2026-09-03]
gen2-st3215/cad/segments/v6/snake_segment_v6_AP203.SLDPRT
89.4 x 33.0 x 46.3 mm

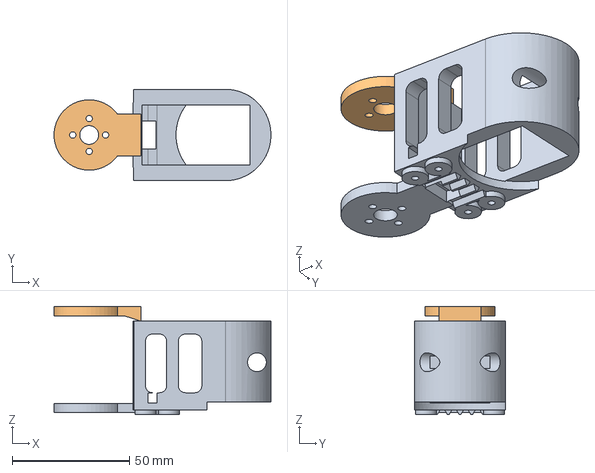
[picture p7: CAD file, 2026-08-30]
gen2-st3215/cad/snake_segment.step
92.5 x 39.0 x 46.1 mm

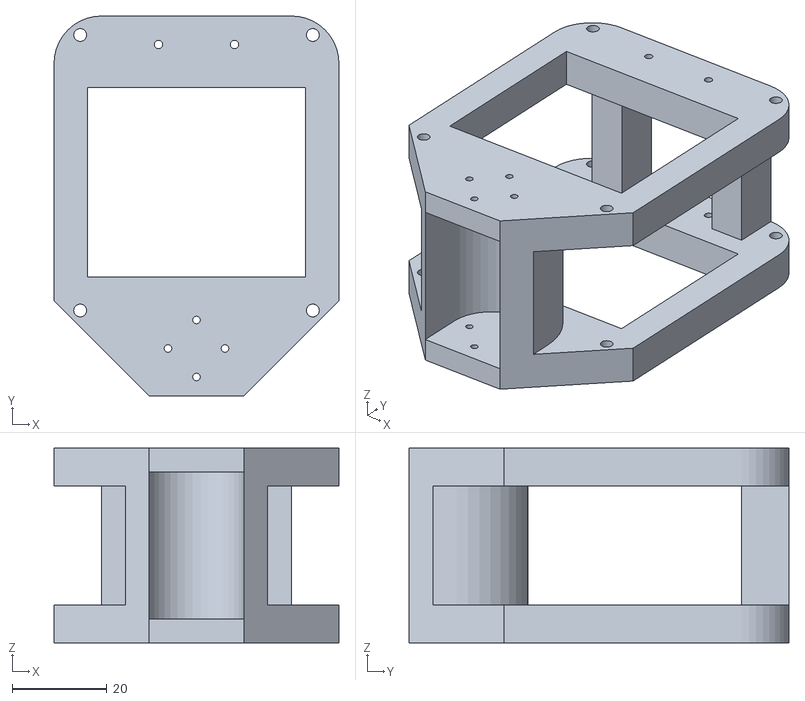
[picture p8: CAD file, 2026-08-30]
gen1-dynamixel/cad/segments/segment2_v1.stl
60.0 x 80.0 x 41.0

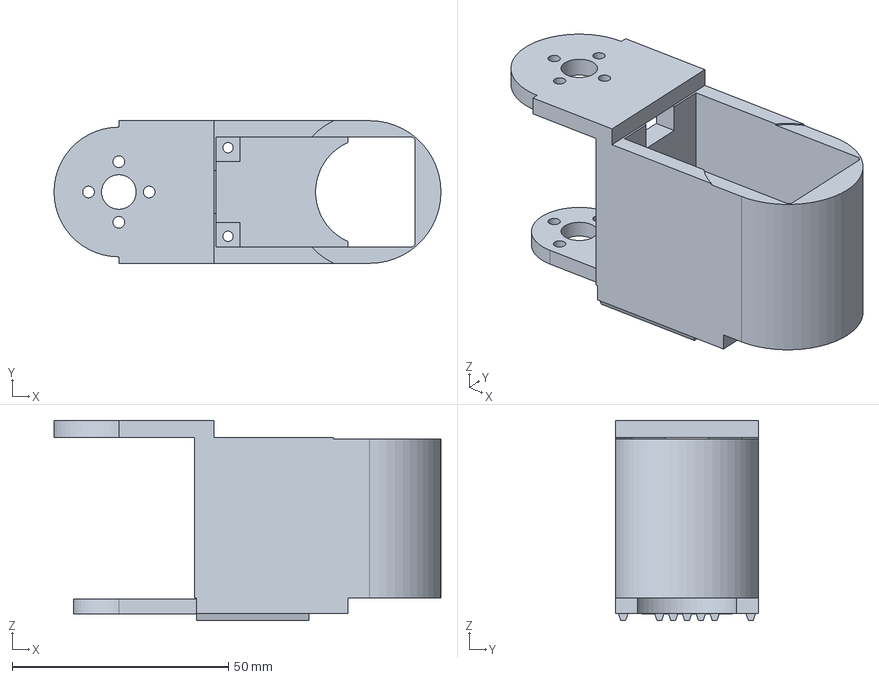
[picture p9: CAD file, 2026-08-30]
gen2-st3215/cad/segments/v6/snake_segment_v6.step
89.5 x 33.0 x 46.3 mm

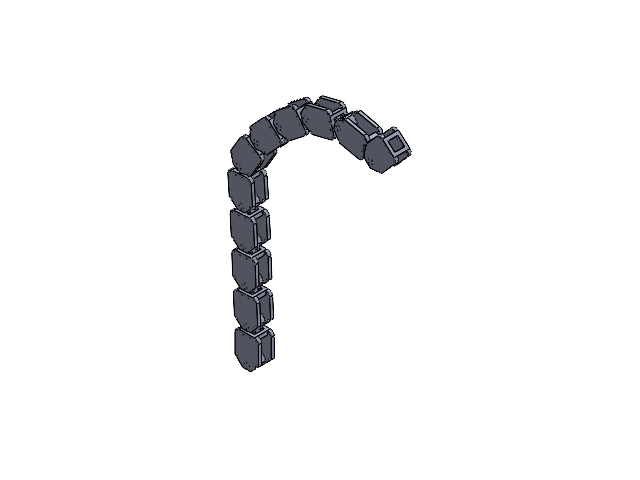
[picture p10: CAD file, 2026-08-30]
gen1-dynamixel/cad/assembly/assembly.SLDASM
segment1 (2) x 11
DC15_A01_CASE_M_DUMMY.stp x 10
DC15_A01_CASE_F_DUMMY.stp x 10
DC15_A01_CASE_B_DUMMY.stp x 10
DC15_A01_HORN_DUMMY.stp x 10
DC15_A01_LED_CAP2_DUMMY.stp x 10
PHS_1_7X20_5_DC10.stp x 40
BTS2_M2_6X8.stp x 20
DC15_A01_HORN_IDLE2_DUMMY.stp x 10
DC15_A01_IDLE_CAP_DUMMY.stp x 10
B3B-EH.stp x 20

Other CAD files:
gen2-st3215/cad/assembly/Assem3.SLDASM
gen2-st3215/cad/final_part/snake_segment_v6_gen1.SLDASM
gen2-st3215/cad/assembly/snake_segment.SLDASM
gen2-st3215/cad/assembly/assemble 1 final.SLDASM
gen2-st3215/cad/motor-ref/Open CASCADE STEP translator 7.9 1.1_5.step.SLDPRT
gen2-st3215/cad/motor-ref/SG-ZIJI_15_4.step.SLDPRT
gen1-dynamixel/cad/segments/segment1.step
gen2-st3215/cad/motor-ref/MOTOR-1723_3_1.step.SLDPRT
gen1-dynamixel/cad/segments/segment1_alt.SLDPRT
gen2-st3215/cad/motor-ref/SG-ZIJI_15_1.step.SLDPRT
gen1-dynamixel/cad/segments/segment2.step
gen1-dynamixel/cad/motor-ref/XL,XC-330.SLDASM
gen1-dynamixel/cad/segments/segment1.SLDPRT
gen1-dynamixel/cad/segments/segment2.SLDPRT
gen2-st3215/cad/motor-ref/GE_27_1.step.SLDPRT
gen2-st3215/cad/motor-ref/GE_27_2.step.SLDPRT
gen2-st3215/cad/motor-ref/GE_27_3.step.SLDPRT
gen2-st3215/cad/motor-ref/GE_27_4.step.SLDPRT
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

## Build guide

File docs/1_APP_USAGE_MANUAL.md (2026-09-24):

# SURGE-090: App Operating Instructions (Gen 2 — ST3215)

> **Updated 24 Sep 2026.** What we did before and what we do now is recorded in [What changed](#what-changed) at the end of this file.

`shared/desktop-app/app.py` is the universal entry point for the Gen 2 robot. Depending on the arguments it runs
either as a headless hardware driver (for the Raspberry Pi 5) or as the Tkinter control dashboard with PyBullet simulation.
Feature list and dependencies: [`../shared/desktop-app/README.md`](../shared/desktop-app/README.md).

---

## 0. How the app talks to the robot

```
app.py (PC or Pi 5)  --USB serial 115200-->  Servo Driver with ESP32  --UART 1 Mbps-->  ST3215 ID1…ID10
                                             running esp32_st3215_receiver
```

| Item | Value |
|---|---|
| Python interface | `gen2-st3215/src/st3215_interface.py` (`ST3215Interface`) |
| ESP32 firmware for app control | `gen2-st3215/firmware/esp32_st3215_receiver/` (OLED + NeoPixel status, USB + ESP-NOW input) |
| Serial | 115200 baud. Port is auto-detected; fallback `COM12` (Windows) or `/dev/ttyUSB0` (Linux/Pi) |
| Position command | `P,1:2048,2:2048,…,10:2048` (0–4095, 2048 = straight) |
| Telemetry request | `T` → reply `T,id:load:speed:pos,…` |
| Set servo ID | `I,<new id>` (only one servo connected) |

> [!IMPORTANT]
> App control uses **`esp32_st3215_receiver`**, not the field firmware. `robot_esp32_v2` runs the gait on the ESP32
> itself and takes `RUN` / `STOP` / `CENTER` / `PING` instead — use it for untethered runs with the base station.
> `esp32_st3215_receiver` has **no** soft start, joint limits or low-battery stop, so on split bus v3 start with
> small amplitudes and keep the loop key within reach.

---

## 1. Headless mode (Raspberry Pi 5 default)

Run the robot with no monitor — the snake slithers in a straight line until you stop it.

```bash
python app.py
```

**What this does:**
- Skips all Tkinter GUI libraries (safe on a headless Pi).
- Auto-detects the ESP32 serial port and connects through `ST3215Interface`.
- Sends a straight-line serpenoid gait at 50 Hz until you press `Ctrl+C`, then closes the port.

*Headless simulation (`python app.py --sim`) is meant to run PyBullet instead of hardware — see Known issues below.*

---

## 2. Graphical dashboard mode (master control suite)

Use this on a laptop to test paths, tune physics, or draw custom paths for the hardware.

```bash
python app.py --gui
```

**What this does:**
- Opens the Tkinter **Master Control Dashboard**.
- Choose **Simulation** (PyBullet 3D) or **Hardware (ST3215 via ESP32 auto-detect)**.
- **Draw a path:** click and drag on the 2D canvas, or type a function like `sin(x)` and generate it.
- **Live telemetry:** angle (°), speed and torque for all 10 joints.
- **Live tuning:** in Simulation mode, drag the sliders in the PyBullet window to change the physics.
- **Auto-stop + accuracy report:** when the snake reaches the end of the path it stops and opens a Matplotlib
  window with the **path-tracking accuracy %**.

---

## 3. Remote GUI access (Raspberry Pi 5 → laptop)

If `app.py --gui` runs on the Pi but you want the window on your laptop:

### Option A: VNC (most reliable)
1. On the Pi: `sudo raspi-config` → *Interface Options* → *VNC* → enable.
2. On the laptop, install **RealVNC Viewer** and connect to the Pi's IP address.
3. In a terminal inside the VNC desktop: `python app.py --gui`.

### Option B: X11 forwarding over SSH (faster, no desktop)
1. Install an X server on the laptop (**VcXsrv** on Windows, **XQuartz** on Mac).
2. Connect with X forwarding (use your own username and hostname):
   ```bash
   ssh -X <user>@<pi-hostname>.local
   ```
3. Run `python app.py --gui`; the window appears on your laptop.

> **Note:** PyBullet (Simulation mode) needs OpenGL and usually fails over X11 forwarding. Use **Hardware** mode when working remotely over SSH.

> **Security:** never write the Pi's password into docs or code. If a password was ever committed, change it on the Pi.

---

## 4. Known issues

- **`app.py --sim` headless still opens the hardware port.** In `run_headless()`, the simulation interface is created
  and then immediately replaced by `ST3215Interface`, so `--sim` without `--gui` tries to connect to the ESP32.
  Use `python app.py --gui` → *Simulation* until this is fixed.
- **`esp32_st3215_receiver` is not yet in `platformio.ini`** and is still a `.ino` file, so it cannot be built with
  `pio run -e …` like the other sketches. Build it with the Arduino IDE (needs the SCServo, Adafruit SSD1306 and
  Adafruit NeoPixel libraries) until an environment is added.

---

## What changed

### 24 Sep 2026

| Topic | Before | Now | Why |
|---|---|---|---|
| Hardware target | Dynamixels on `COM3` | ST3215 via ESP32 running `esp32_st3215_receiver`, 115200 baud, port auto-detected (fallback `COM12`) | `app.py` already used ST3215; the manual lagged behind |
| Safety note | — | Warning that the receiver firmware has no soft start or limits | Split bus v3 fuses and joint limits |
| SSH example | Contained the Pi password | Password removed | Credentials must not be in docs |
| Known issues | — | `--sim` headless bug; receiver not in `platformio.ini` | Found while checking the code |

<details>
<summary>Previous version of this document (before 24 Sep 2026) — password removed</summary>

# Snake SURGE: Operating Instructions

The `app.py` script is your **Universal Entry Point**. Depending on the arguments you use, it acts as either a lightweight physical hardware driver for the Raspberry Pi, or a massive Tkinter Control Dashboard with simulation tools.

---

## 1. Headless Mode (Raspberry Pi Default)
When running the robot on a headless Raspberry Pi without a monitor, you just want the snake to turn on and slither physically forward in a straight line.

Run the following command:
```bash
python app.py
```
**What this does:**
- Bypasses all Tkinter GUI libraries entirely (so it won't crash on a headless Pi).
- Automatically targets `COM3` (Windows) or `/dev/ttyUSB0` (Linux/Raspberry Pi) to connect to physical Dynamixels.
- Loads a straight-line Path Engine and slithers infinitely until you press `Ctrl+C`.

*(If you want to test the headless logic using PyBullet instead of physical motors, run: `python app.py --sim`)*

---

## 2. Graphical Dashboard Mode (Master Control Suite)
Use this mode on your laptop to test paths, tune physics, or draw custom paths for the hardware.

Run the following command:
```bash
python app.py --gui
```
**What this does:**
- Opens the Tkinter **Master Control Dashboard**.
- Allows you to choose between **Simulation Mode** (PyBullet 3D Engine) or **Hardware Mode** (Dynamixel COM3).
- **Draw a Path**: Click and drag your mouse on the 2D canvas, or type a mathematical function like `sin(x)`.
- **Live Tuning**: In Simulation mode, you can drag the sliders inside the 3D PyBullet window to actively alter the snake's physics!
- **Auto-Stop & Accuracy Report**: When the snake finishes tracking your path, it auto-stops and pops up a native Matplotlib window detailing its exact **Path Tracking Accuracy %**.

---

## 3. Remote GUI Access (Raspberry Pi to Laptop)
If you are running the `python app.py --gui` command from your laptop but the code is actually executing on the Raspberry Pi across the room:

### Option A: VNC Server (Recommended for visual reliability)
1. On the Pi, enable VNC: `sudo raspi-config` > `Interface Options` > `VNC`.
2. On your laptop, download **RealVNC Viewer** and connect to the Pi's IP address.
3. Open a terminal inside the VNC desktop and run `python app.py --gui`.

### Option B: X11 Forwarding over SSH (Faster, no desktop needed)
1. Install an X-Server on your laptop (e.g., **VcXsrv** for Windows, **XQuartz** for Mac).
2. Open **PowerShell** and connect to your Pi using the `-X` flag:
   ```bash
   ssh -X smartsnake@snakerobo.local
   ```
   *(If it asks for a fingerprint, type `yes`. When prompted for the password, type `[password removed]`)*
3. Run `python app.py --gui`. The Tkinter window will forward over WiFi and appear directly on your laptop screen!
> **Note:** PyBullet's 3D engine (`Simulation Mode`) requires heavy OpenGL and will likely crash over X11 forwarding. It is highly recommended to only use **Hardware Mode** when operating the Pi remotely over SSH!

</details>

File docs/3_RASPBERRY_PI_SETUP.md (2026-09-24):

# SURGE-SNAKE: Raspberry Pi Setup & Execution Guide

This guide will walk you through flashing the OS, deploying this code to your Raspberry Pi, and running the physical robot.

---

## 🚀 TL;DR: Daily Launch Sequence (Windows cmd.exe)
*Follow these steps **every time** you boot your Pi and want to run your project with a GUI popping up on your Windows PC.*

1. **Power on the Pi:** Wait 1-2 minutes for it to boot and connect to Wi-Fi.
2. **Start the Windows X-Server:** 
   - Open **XLaunch** from your Windows Start menu.
   - Click *Next* until the "Extra settings" screen.
   - **CRITICAL:** Check **"Disable access control"**, then click Finish.
3. **Open Command Prompt (`cmd.exe`):**
   - Press Win+R, type `cmd`, and press Enter.
4. **Connect via SSH with X11 Forwarding:**
   - Run the following two commands exactly as written:
     ```cmd
     set DISPLAY=localhost:0.0
     ssh -Y smartsnake@snakerobo.local
     ```
     *(Change `smartsnake@snakerobo.local` if your username or hostname is different, e.g., `smartsnake@snakerobo.local`).*
5. **Run Your Code:**
   - Navigate to your project folder: `cd SURGE-SNAKE`
   - Run your Python script: `python3 main.py`
   - Your GUI window will now automatically pop up on your Windows PC!

---
## Phase 1: Burning the Raspberry Pi OS
Since the Pi will sit inside the snake, it will run "headless" (without a monitor).

1. **Download Raspberry Pi Imager:** Install it on your Windows PC from the official Raspberry Pi website.
2. **Insert SD Card:** Plug the 32GB SD card into your PC.
3. **Configure Imager:**
   - **Device:** Select `Raspberry Pi 4`.
   - **OS:** Choose `Raspberry Pi OS (64-bit)` (Lite is fine if you don't need a desktop UI, otherwise choose Full).
   - **Storage:** Select your 32GB SD Card.
4. **OS Customization (Crucial for Headless Setup):**
   - Click the gear icon (or "Edit Settings") before writing.
   - Check **Set hostname** (e.g., `snakerobo.local`).
   - Check **Enable SSH** (Use password authentication).
   - Set **Username and Password** (e.g., user: `pi`, pass: `password`).
   - Check **Configure wireless LAN** and enter your home Wi-Fi SSID and Password.
5. **Write:** Click "Write" to burn the OS.

---

## Phase 2: Hardware Wiring & Booting
1. Insert the flashed SD card into the Raspberry Pi.
2. Plug the USB-C 5V 3A adapter into the Pi to boot it up.
3. Plug the **U2D2 Interface** into one of the Pi's USB ports.
4. Connect the **5V 10A Power Supply** to the **U2D2 PHB Power Board** (Double check positive/negative polarity!).
5. Daisy-chain your 2 Dynamixel motors to the U2D2 PHB.

---

## Phase 3: Accessing the Pi and Installing Dependencies
Wait about 2 minutes for the Pi to boot and connect to your Wi-Fi.

1. Open PowerShell on your Windows PC and SSH into the Pi:
   ```bash
   ssh smartsnake@snakerobo.local
   ```
   *(Accept the fingerprint prompt and enter your password).*
2. Once inside the Pi, update the system:
   ```bash
   sudo apt update
   sudo apt upgrade -y
   ```

3. **Install Python Libraries:**
   On the newest Raspberry Pi OS (Bookworm and later), you cannot use standard `pip install` globally without getting an "externally-managed-environment" error. 

   **Method A: System Packages (Best for large libraries like Matplotlib)**
   ```bash
   sudo apt install python3-flask python3-psutil python3-serial python3-pip
   ```

   **Method B: The Quick Override (If a library isn't in apt)**
   ```bash
   pip install pybullet --break-system-packages
   ```

   **Method C: Python Virtual Environment (Best Practice)**
   ```bash
   python3 -m venv ~/snake_env
   source ~/snake_env/bin/activate
   pip install flask psutil pyserial pybullet
   ```
   *(If you use a venv, remember you must run `source ~/snake_env/bin/activate` before running your code every time).*

4. Add your user to the `dialout` group so Python can access the USB port without root permissions:
   ```bash
   sudo usermod -aG dialout smartsnake
   ```
   *You must log out and log back in (or reboot the Pi) for this to take effect.*

---

## Phase 4: Copying the Code (Windows to Pi)
You have this `SURGE-SNAKE` folder on your Windows Desktop. We need to send it to the Pi.

### Method A: Using SCP (Command Line)
Open a **new** PowerShell window on your Windows PC (not the SSH session) and run:
```bash
scp -r "C:\Users\bansi\OneDrive\Desktop\SURGE-SNAKE" smartsnake@snakerobo.local:/home/smartsnake/
```
This will copy the entire folder over the network.

### Method B: Using WinSCP (GUI)
1. Download and install [WinSCP](https://winscp.net/).
2. Connect to `snakerobo.local` using your Pi's username and password.
3. Drag and drop the `SURGE-SNAKE` folder from your desktop into the `/home/smartsnake/` directory.

> **Note on USB Ports:** 
> I have already updated the Python scripts to automatically detect that they are running on a Raspberry Pi (Linux) and they will look for the U2D2 at `/dev/ttyUSB0` instead of `COM3`. You do not need to manually change the code!

---

## Phase 5: Testing & Running
SSH back into your Pi (`ssh smartsnake@snakerobo.local`) and navigate to the folder:
```bash
cd SURGE-SNAKE
```

**1. Ping the Motors:**
```bash
python3 tests/test_dynamixel_ping.py
```
*You should see output confirming communication with Motor 1 and Motor 2.*

**2. Test Obstacle Load Detection:**
```bash
python3 tests/test_motor_feedback.py
```
*Squeeze the motor lightly while it spins; watch the current/mA reading spike.*

**3. Run the Main Snake Loop:**
```bash
python3 main.py
```
*The motors will begin executing the rolling helix wave. If you grab one, it will trigger the reverse-and-turn evasion sequence!*

---

## Phase 6: Monitoring Raspberry Pi Health & Hardware

Because the Pi 5 runs hotter and faster, monitoring its performance and temperature is important.

### Checking CPU Temp & Fan Speed
- **CPU Temperature:** `vcgencmd measure_temp` (gives `temp=48.2'C`)
- **Fan RPM:** `cat /sys/devices/platform/cooling_fan/hwmon/*/fan1_input` (returns 0 if fan is off)
- **Live Monitor:** Refresh both every 2 seconds by running:
  ```bash
  watch -n 2 "vcgencmd measure_temp && echo 'Fan RPM:' && cat /sys/devices/platform/cooling_fan/hwmon/*/fan1_input"
  ```

*Note on Fan Orientation: The side with the technical sticker is the side air flows out of. If mounting directly on the Pi 5 CPU/heatsink, the sticker side should face DOWN towards the board.*

### Hardware & Resource Stats
- **All-in-One Visual Dashboard:** Install `btop` (`sudo apt install btop`) and run `btop`.
- **RAM Usage:** `free -h`
- **Storage Space:** `df -h /`
- **CPU Architecture details:** `lscpu`
- **Board Map:** `pinout`

---

## Phase 7: GUI X11 Forwarding on Windows (Using cmd.exe)

If you need to view a GUI application running on the headless Raspberry Pi directly on your Windows PC monitor, follow these steps.

**1. Install VcXsrv (XLaunch) on Windows:**
- Download and install VcXsrv.
- Run XLaunch. On the "Extra settings" screen, you **must** check **"Disable access control"**.

**2. Configure the Raspberry Pi:**
- Ensure X11 authentication is installed: `sudo apt install xauth`
- Edit the SSH config: `sudo nano /etc/ssh/sshd_config`
- Add or modify the following lines (uncomment them if necessary):
  ```plaintext
  X11Forwarding yes
  X11UseLocalhost no
  AddressFamily inet
  ```
- Restart the SSH service: `sudo systemctl restart ssh`
- Type `exit` to disconnect.

**3. Connect from Windows using cmd.exe:**
Open your Windows `cmd.exe` prompt and set the display variable before connecting. The `-Y` flag enables trusted X11 forwarding.
```cmd
set DISPLAY=localhost:0.0
ssh -Y smartsnake@snakerobo.local
```
*(If you were using PowerShell, the command would be `$env:DISPLAY="localhost:0.0"`)*

**4. Test the GUI Connection:**
On the Pi, check that the variable is set:
```bash
echo $DISPLAY
```
*(It should output something like `localhost:10.0`)*. 
To test, install `sudo apt install x11-apps` and run `xeyes`. A window with cartoon eyes should pop up on your Windows desktop!

---

## Phase 8: Running Small LLMs (Ollama)

To run local LLMs (e.g., to control the Snake), stick to smaller, quantized models (1B to 3B parameters) since the Pi 5 runs inference entirely on the CPU.

**Recommended Models:**
- `Gemma 3 (1B)` or `Llama 3.2 (1B)`: ~15-20 tokens/sec. Fast and fluid.
- `Llama 3.2 (3B)` or `Qwen 2.5 Coder (3B)`: ~5-8 tokens/sec. Smarter but slower.

**Implementation Tips for Snake:**
- **Prompting:** Small models struggle with spatial reasoning (2D arrays). Instead of an ASCII grid, provide explicit coordinates (e.g., *Your head is at (5,5), Apple is at (7,5)*).
- **Chain-of-Thought:** Ask the LLM to output its rationale before making a move.
- **Tools:** Use frameworks like `SnakeBench` or custom LangChain setups to connect your Python game loop with the Ollama server.

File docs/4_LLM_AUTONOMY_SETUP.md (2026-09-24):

# LLM Autonomy Setup on Raspberry Pi 5

This guide details how to turn your Raspberry Pi 5 into the "Brain" of the Snake SURGE robot using lightweight Local LLMs.

## 1. Installing Ollama

Ollama is the easiest and most optimized way to run LLMs locally on ARM processors like the Raspberry Pi 5.

To install it, open a terminal on your Raspberry Pi and run:
```bash
curl -fsSL https://ollama.com/install.sh | sh
```
Ollama runs as a background service and exposes a REST API on `localhost:11434`.

## 2. Best Models for Raspberry Pi 5

The Pi 5 relies entirely on its CPU and RAM for AI (it does not have a dedicated AI accelerator out of the box). Therefore, we must use heavily quantized (compressed), small parameter models to achieve real-time responsiveness.

We highly recommend **avoiding Vision/Image models (like LLaVA)**. Analyzing camera frames with a local LLM on a Pi 5 takes several seconds per frame, which is far too slow for real-time robotic control. 

Instead, use these text-based reasoning models:

| Model | Command | RAM Needed | Speed on Pi 5 | Use Case |
|---|---|---|---|---|
| **Qwen 2.5 (0.5B)** | `ollama run qwen2.5:0.5b` | ~0.7 GB | ⚡ Very Fast | Best for rapid JSON outputs and basic steering decisions. |
| **Llama 3.2 (1B)** | `ollama run llama3.2:1b` | ~1.5 GB | 🟢 Fast | Great balance of speed and logical reasoning for obstacle avoidance. |
| **Llama 3.2 (3B)** | `ollama run llama3.2` | ~2.5 GB | 🟡 Moderate | Excellent reasoning, but might cause control-loop lag. |

> [!TIP]
> Start with **Llama 3.2 (1B)**. It is specifically designed by Meta for edge devices and excels at tool calling and JSON formatting.

## 3. Data Processing Architecture (How it Thinks)

Because processing images is too slow, we will feed the LLM **Telemetry & Sensor Data** in plain text (JSON). The LLM acts as the "Decision Maker", while your Python code acts as the "Reflexes".

### What Data goes IN to the LLM?
Instead of a camera, your Python script will construct a text prompt describing the snake's environment based on cheap sensors (like Ultrasonic or LiDAR) and math:
```json
{
  "system_goal": "Reach coordinate (10, 5).",
  "current_pose": {"x": 2.5, "y": 1.0, "heading": "45 degrees"},
  "sensors": {
    "front_obstacle_distance": "0.3m",
    "left_obstacle_distance": "1.2m",
    "right_obstacle_distance": "0.1m"
  }
}
```

### What Data comes OUT of the LLM?
The LLM will be instructed to only reply with a JSON command block. It evaluates the prompt above ("There's an obstacle right in front of me and to my right, but the left is clear") and outputs:
```json
{
  "reasoning": "Obstacle imminent ahead and right. Must steer left to avoid collision while progressing towards target.",
  "command": {
    "turn_offset": 0.5,
    "speed": 0.5
  }
}
```

Your `web_app.py` control loop will parse this JSON and instantly apply `turn_offset = 0.5` to the kinematics engine, forcing the snake to smoothly curve left!

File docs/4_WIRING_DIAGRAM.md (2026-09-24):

# SURGE-090 Wiring & Circuit Diagram — Gen 2 (ST3215, split power bus v3)

> **Updated 24 Sep 2026.** What we did before and what we do now is recorded in [What changed](#what-changed) at the end of this file.

This is the current wiring for the Gen 2 robot: 10× Waveshare ST3215 servos, one
Waveshare Servo Driver with ESP32, and a 3S LiPo on **split power bus v3**.

- Power design and numbers: [`hardware/power_split_bus_v3.md`](hardware/power_split_bus_v3.md)
- Full drawing: [`hardware/wiring_split_bus_v3.svg`](hardware/wiring_split_bus_v3.svg)
- Firmware for this wiring: `gen2-st3215/firmware/robot_esp32_v2/`
- Gen 1 (Dynamixel XL330 + U2D2) wiring is kept in [`../gen1-dynamixel/docs/wiring_diagram.md`](../gen1-dynamixel/docs/wiring_diagram.md)

> The one rule of v3: **DATA and GND run as one continuous wire from the controller to ID10. +12 V is cut before every inject board**, so each pair of servos is powered only by its own fused feed.

## 1. Block diagram

```mermaid
graph LR
    subgraph Robot
        BAT[3S LiPo 1800 mAh<br/>11.1–12.6 V, XT60] --> F15[15 A fuse] --> KEY[XT60 loop key]
        KEY --> MAIN[Main line +12 V / GND<br/>16–18 AWG]
        MAIN --> BUCK[Buck set to 7.5 V] --> DRV[Servo Driver with ESP32<br/>robot_esp32_v2]
        DRV -- "Servo port: GND + DATA only (+V cut)" --> I1
        MAIN -- "3 A" --> I1[Inject 1] --> S12[ID1 → ID2]
        S12 -- "GND + DATA" --> I2
        MAIN -- "3 A" --> I2[Inject 2] --> S34[ID3 → ID4]
        S34 -- "GND + DATA" --> I3
        MAIN -- "3 A" --> I3[Inject 3] --> S56[ID5 → ID6]
        S56 -- "GND + DATA" --> I4
        MAIN -- "3 A" --> I4[Inject 4] --> S78[ID7 → ID8]
        S78 -- "GND + DATA" --> I5
        MAIN -- "3 A" --> I5[Inject 5] --> S910[ID9 → ID10]
        IMU[MPU6050] -- "I²C SDA 21 / SCL 22" --> DRV
    end
    subgraph Base station
        ESP2[ESP32 #2<br/>base_esp32] -- "USB serial 115200" --> PI[Raspberry Pi 5<br/>base_station.py]
    end
    DRV <-. "ESP-NOW 2.4 GHz" .-> ESP2
```

## 2. Connection tables

### Power

| From | To | Wire | Notes |
|---|---|---|---|
| 3S LiPo + | 15 A fuse → XT60 loop key → main line +12 V | 16–18 AWG silicone | Loop key is the master ON/OFF |
| 3S LiPo − | Main line GND | 16–18 AWG silicone | All grounds are joined |
| Main line | Buck converter IN | short | Set buck output to **7.5 V before** connecting the controller |
| Buck OUT 7.5 V | Servo Driver DC jack | — | Controller power only |
| Main line +12 V | Each inject board, through a **3 A fuse** (blade or PTC) | 20–22 AWG, short | 5 taps total |
| Main line GND | Each inject board GND | 20–22 AWG | — |
| Main line | Along the body | — | Leave ~30 mm slack at every joint |

### Servo bus (one UART, IDs 1–10)

| From | To | Pins carried |
|---|---|---|
| Servo Driver servo port 1 | Inject 1 IN | GND + DATA (**+V wire cut and taped**). Port 2 stays empty |
| Inject *n* OUT (3-pin plug) | First servo of group *n* | +12 V · GND · DATA |
| Servo → next servo inside a group | Standard ST3215 lead | +12 V · GND · DATA |
| Last servo of group *n* | Inject *n+1* IN | GND + DATA through, **+V cut** |

| Group | Servos | Inject board sits before |
|---|---|---|
| G1 | ID1–ID2 | ID1 (next to the controller) |
| G2 | ID3–ID4 | ID3 |
| G3 | ID5–ID6 | ID5 |
| G4 | ID7–ID8 | ID7 |
| G5 | ID9–ID10 | ID9 |

### Inside one inject board (small perfboard, 5 total)

| Input | Goes to |
|---|---|
| From previous servo/controller: GND | Through to OUT GND |
| From previous servo/controller: DATA | Through to OUT DATA |
| From previous servo/controller: +V | **Cut ✕ — not connected** |
| From main line: +12 V via 3 A fuse | OUT +V |
| From main line: GND | OUT GND |
| Across OUT +12 V / GND | 470 µF 25 V capacitor |

### Logic and radio

| Signal | ESP32 pin | Notes |
|---|---|---|
| Servo UART RX / TX | GPIO 18 / 19 @ 1 Mbps | On the Waveshare board. If `PING` finds nothing, check these, the GND link and servo power |
| MPU6050 SDA / SCL | GPIO 21 / 22, address 0x68 | Optional — the gait runs without it |
| Base station | ESP32 #2 on the Pi 5 USB port, 115200 baud | Robot ↔ base over ESP-NOW; no wires |

## 3. Current per group

| Condition | Current (per group of 2) |
|---|---|
| Walking | ~0.6–1.0 A |
| Heavy load | ≤ 1.8 A |
| Both servos stalled | 5.4 A → the 3 A fuse opens and protects the plugs |

Total from the battery while walking is about 3–5 A. If fuses trip when all servos move at power-up,
`robot_esp32_v2` already soft-starts one group at a time; if it still trips, use 4 A fuses.

## 4. Build and test order

1. **Before any servo is connected:** battery → fuse → loop key → main line. The meter should read 12.x V.
2. Set the buck to **7.5 V**, then connect the Servo Driver.
3. **Set servo IDs first** (all ST3215s ship as ID 1): connect one servo at a time and use the
   `assign_ids` firmware or `gen2-st3215/tools/assign_id.py` to set IDs 1–10.
4. Connect **group 1 only** (ID1–2). Flash `robot_esp32_v2`, open the serial monitor at 115200 and type `PING`.
5. Add groups 2 → 5 one at a time, checking for 12 V at each inject board and running `PING` after each.
6. Type `CENTER` and fit the horns with every joint straight. Type `STOP`.
7. Type `RUN` for a slow gait. Every servo should report ≥ 11.7 V in telemetry.

## 5. Safety

- **Never** connect the Mean Well 5 V supply (or any 5 V rail) to the servo line or driver VIN.
- Keep the loop key **out** while wiring. Disconnect the battery before touching inject boards.
- The firmware stops the robot at 10.2 V (3.4 V/cell) and at 70 °C, but a LiPo alarm/BMS is still recommended.
- Check that the Ø8 mm cable tunnel in each v6 segment fits the 2 main-line wires plus the servo lead.

---

## What changed

### 24 Sep 2026

| Topic | Before | Now | Why |
|---|---|---|---|
| Robot generation | Gen 1: 10× Dynamixel XL330 via U2D2 + PHB | Gen 2: 10× Waveshare ST3215 via Servo Driver with ESP32 | Only 2 XL330s could be bought before the part became unavailable in India |
| Power | 5 V 10 A mains supply into the U2D2 PHB (tethered) | 3S LiPo on split bus v3 (untethered) | ST3215 needs 6–12.6 V; Each plug carries only 2 servos' current, a jam takes out only 2 joints, and the voltage drop is almost zero (see `power_split_bus_v3.md`) |
| Compute / link | Raspberry Pi 4 on the robot, USB to U2D2 | ESP32 on the robot; Pi 5 base station over ESP-NOW | Robot runs untethered |

<details>
<summary>Previous version of this document (before 24 Sep 2026) — Gen 1 Dynamixel wiring, also in <code>gen1-dynamixel/docs/wiring_diagram.md</code></summary>

# SURGE-SNAKE Wiring & Circuit Diagram

This document contains the exact wiring instructions and a visual flowchart showing how power and data travel through your robot.

## 1. Visual Flowchart
*If your markdown viewer supports Mermaid, this will render as a visual flowchart. Otherwise, follow the text-based connections below.*

```mermaid
graph TD
    subgraph Power Source (Mains)
        Wall[Wall Outlet AC] -->|AC Input| PS[5V 10A Power Supply]
        PS -->|Red Wire / V+| PHB_V[U2D2 PHB Terminal: +]
        PS -->|Black Wire / V-| PHB_G[U2D2 PHB Terminal: -]
    end

    subgraph Computing Brain
        PiPS[Official USB-C Pi Adapter] -->|5V 3A Power| PI[Raspberry Pi 4]
        PI <-->|Data: USB A to Micro USB| U2D2[U2D2 USB Interface]
    end

    subgraph Motor Network (Daisy Chain)
        U2D2 -->|Plugs Directly On Top| PHB[U2D2 PHB Power Hub]
        PHB_V --> PHB
        PHB_G --> PHB
        
        PHB <-->|X3P Robot Cable| M1[Dynamixel XL330 Motor 1]
        M1 <-->|X3P Robot Cable| M2[Dynamixel XL330 Motor 2]
        M2 <-.->|X3P Robot Cable| M10[Dynamixel XL330 Motor 10]
    end
    
    subgraph Future Head Sensors
        PI -.->|Bluetooth / WiFi Data| ESP[ESP32 Microcontroller]
        ESP <-->|Jumper Wires| SEN[HC-SR04 / VL53L0X Sensor]
    end

    style PS fill:#f9d0c4,stroke:#333,stroke-width:2px
    style PI fill:#c4e3f9,stroke:#333,stroke-width:2px
    style PHB fill:#d4f9c4,stroke:#333,stroke-width:2px
    style M1 fill:#fff2cc,stroke:#333
    style M2 fill:#fff2cc,stroke:#333
    style M10 fill:#fff2cc,stroke:#333
```

---

## 2. Step-by-Step Exact Wiring Instructions

### Step 1: Powering the Pi
1. Plug the **Official Raspberry Pi USB-C Power Adapter** into the wall.
2. Plug the USB-C end into the **Raspberry Pi 4**.
   - *Safety Note: NEVER try to power the Pi from the U2D2 or the 10A power supply. Always keep its power isolated via the official adapter to prevent blowing the Pi's fuses.*

### Step 2: The Motor Power Supply
1. Take your **5V 10A Power Supply**. Wire its AC input terminals (L, N, G) to a standard wall plug cable.
2. Take two thick wires (18 AWG recommended). 
3. Connect one wire to the **V+** terminal on the power supply, and the other to the **V- (or COM)** terminal.
4. On the **U2D2 PHB Power Hub Board**, locate the 2-pin screw terminal block.
5. Screw the **V+** wire into the **+** slot on the PHB.
6. Screw the **V-** wire into the **-** slot on the PHB.

### Step 3: The Data Bridge
1. The **U2D2 USB Interface** is a small stick. It physically mounts onto the pins of the **U2D2 PHB Power Hub Board**. Press it down firmly so the pins mate.
2. Use a Micro-USB to USB-A cable. Plug the Micro end into the **U2D2 USB Interface**, and plug the USB-A end into any USB 3.0 (blue) port on the **Raspberry Pi 4**.
   - *This provides the data link between the Pi's Python script and the motors.*

### Step 4: The Daisy Chain (Motors)
1. The XL330 motors have two identical ports on the back.
2. Take a **Robot Cable X3P**. Plug one end into any 3-pin TTL port on the **U2D2 PHB Power Hub Board**.
3. Plug the other end into either port on **Motor 1**.
4. Take a second **Robot Cable X3P**. Plug it into the remaining port on **Motor 1**.
5. Plug the other end into **Motor 2**.
6. Repeat this process for all remaining motors. Because the ports are identical, it does not matter which of the two ports on the motor is "in" or "out".

### Step 5: Setting Motor IDs (Crucial!)
Out of the box, all Dynamixel motors have an ID of `1`. If you daisy-chain them immediately, the code will fail because it cannot distinguish between them.
1. Plug in **only ONE motor** to the U2D2 PHB.
2. Use the **Dynamixel Wizard 2.0** software on your Windows PC to change its ID to `1`.
3. Unplug it. Plug in the next motor. Change its ID to `2`.
4. Repeat until you have motors 1 through 10. *Only then* can you daisy chain them all together at once!

</details>

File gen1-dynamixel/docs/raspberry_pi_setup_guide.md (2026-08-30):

# SURGE-SNAKE: Raspberry Pi Setup & Execution Guide

This guide will walk you through flashing the OS, deploying this code to your Raspberry Pi, and running the physical robot.

## Phase 1: Burning the Raspberry Pi OS
Since the Pi will sit inside the snake, it will run "headless" (without a monitor).

1. **Download Raspberry Pi Imager:** Install it on your Windows PC from the official Raspberry Pi website.
2. **Insert SD Card:** Plug the 32GB SD card into your PC.
3. **Configure Imager:**
   - **Device:** Select `Raspberry Pi 4`.
   - **OS:** Choose `Raspberry Pi OS (64-bit)` (Lite is fine if you don't need a desktop UI, otherwise choose Full).
   - **Storage:** Select your 32GB SD Card.
4. **OS Customization (Crucial for Headless Setup):**
   - Click the gear icon (or "Edit Settings") before writing.
   - Check **Set hostname** (e.g., `surgesnake.local`).
   - Check **Enable SSH** (Use password authentication).
   - Set **Username and Password** (e.g., user: `pi`, pass: `password`).
   - Check **Configure wireless LAN** and enter your home Wi-Fi SSID and Password.
5. **Write:** Click "Write" to burn the OS.

---

## Phase 2: Hardware Wiring & Booting
1. Insert the flashed SD card into the Raspberry Pi.
2. Plug the USB-C 5V 3A adapter into the Pi to boot it up.
3. Plug the **U2D2 Interface** into one of the Pi's USB ports.
4. Connect the **5V 10A Power Supply** to the **U2D2 PHB Power Board** (Double check positive/negative polarity!).
5. Daisy-chain your 2 Dynamixel motors to the U2D2 PHB.

---

## Phase 3: Accessing the Pi and Installing Dependencies
Wait about 2 minutes for the Pi to boot and connect to your Wi-Fi.

1. Open PowerShell on your Windows PC and SSH into the Pi:
   ```bash
   ssh pi@surgesnake.local
   ```
   *(Accept the fingerprint prompt and enter your password).*
2. Once inside the Pi, update the system and install the required Python libraries:
   ```bash
   sudo apt update
   sudo apt upgrade -y
   sudo apt install python3-pip
   pip install dynamixel-sdk pyserial
   ```
3. Add your user to the `dialout` group so Python can access the USB port without root permissions:
   ```bash
   sudo usermod -aG dialout pi
   ```
   *You must log out and log back in (or reboot the Pi) for this to take effect.*

---

## Phase 4: Copying the Code (Windows to Pi)
You have this `SURGE-SNAKE` folder on your Windows Desktop. We need to send it to the Pi.

### Method A: Using SCP (Command Line)
Open a **new** PowerShell window on your Windows PC (not the SSH session) and run:
```bash
scp -r ./surge090 <user>@<host>:~/
```
This will copy the entire folder over the network.

### Method B: Using WinSCP (GUI)
1. Download and install [WinSCP](https://winscp.net/).
2. Connect to `surgesnake.local` using your Pi's username and password.
3. Drag and drop the `SURGE-SNAKE` folder from your desktop into the `/home/pi/` directory.

> **Note on USB Ports:** 
> I have already updated the Python scripts to automatically detect that they are running on a Raspberry Pi (Linux) and they will look for the U2D2 at `/dev/ttyUSB0` instead of `COM3`. You do not need to manually change the code!

---

## Phase 5: Testing & Running
SSH back into your Pi (`ssh pi@surgesnake.local`) and navigate to the folder:
```bash
cd SURGE-SNAKE
```

**1. Ping the Motors:**
```bash
python3 tests/test_dynamixel_ping.py
```
*You should see output confirming communication with Motor 1 and Motor 2.*

**2. Test Obstacle Load Detection:**
```bash
python3 tests/test_motor_feedback.py
```
*Squeeze the motor lightly while it spins; watch the current/mA reading spike.*

**3. Run the Main Snake Loop:**
```bash
python3 main.py
```
*The motors will begin executing the rolling helix wave. If you grab one, it will trigger the reverse-and-turn evasion sequence!*

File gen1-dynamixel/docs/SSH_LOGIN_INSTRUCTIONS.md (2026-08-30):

# Raspberry Pi SSH Login Instructions

These are the step-by-step instructions to log into the Raspberry Pi from your Windows computer.

## Prerequisites
- Ensure your Raspberry Pi is powered on.
- Ensure your Raspberry Pi is on the same network as your PC. This means EITHER:
  - You have an **Ethernet cable** directly connecting the Pi to your PC.
  - OR, both devices are connected to the same **Wi-Fi network / hotspot**.

## Login Steps

**Step 1: Open PowerShell**
1. Press the **Windows Key** on your keyboard.
2. Type `PowerShell` and press **Enter**.

**Step 2: Enter the SSH Command**
In the PowerShell window, type the following command and press **Enter**:
```powershell
ssh smartsnake@snakerobo.local
```

**Step 3: Security Prompt (First Time Only)**
If you see a message asking: `Are you sure you want to continue connecting (yes/no/[fingerprint])?`
Type `yes` and press **Enter**.

**Step 4: Enter Password**
When prompted for the password, type:
```text
<REDACTED — set your own; never commit>
```
*Note: The password will **not** appear on the screen as you type it. This is a normal security feature. Just type the characters and press **Enter**.*

> **⚠️ Security:** Change the default Raspberry Pi password immediately after first login using the `passwd` command.

## Success!
Once you see the prompt change to `smartsnake@snakerobo:~ $`, you are successfully logged into the Raspberry Pi and can start running commands.

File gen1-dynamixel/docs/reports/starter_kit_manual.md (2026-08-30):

# Snake Robot Starter Kit Manual (Dynamixel Edition)

Welcome to the Starter Kit for the self-adaptive snake robot project! This manual focuses on testing individual motor movement, reading current (load) feedback, and testing the `dynamixel_sdk` using Python.

By the end of this guide, you will have your first Dynamixel XL330 motor spinning and reporting its load back to your computer.

---

## 1. Hardware Requirements for Testing

To begin testing, you need the following connected to your computer:
1. **Dynamixel XL330-M288 Motor** (At least 1 unit, though you can daisy chain 2 for this test)
2. **Robotis U2D2** (USB to TTL interface)
3. **U2D2 Power Hub Board (PHB)** (To inject power into the data line)
4. **5V Power Supply** (e.g., Mean Well SMPS or a 5V bench power supply capable of at least 3A)
5. **Dynamixel X3P Cables** (To connect everything together)

---

## 2. Hardware Assembly

1. Connect the **U2D2** to your computer via USB.
2. Mount the **U2D2 Power Hub Board** onto the U2D2.
3. Wire the **5V Power Supply** to the screw terminals on the Power Hub Board. Make sure the polarity (+ and -) is correct.
4. Plug one end of the **X3P Cable** into the Power Hub Board, and the other end into your **Dynamixel XL330** motor.
5. Turn on the 5V power supply. The LED on the back of the Dynamixel motor should flash red once to indicate it has power.

---

## 3. Software Setup (Python)

We are using Python to control the snake robot, relying on the official `dynamixel_sdk`.

### Step 3.1: Identify the COM Port
- **Windows:** Open Device Manager, look under "Ports (COM & LPT)" and find the "USB Serial Port". Note the number (e.g., `COM3`).
- **Linux/Raspberry Pi:** Open a terminal and run `ls /dev/ttyUSB*`. It will usually be `/dev/ttyUSB0`.

### Step 3.2: Install Requirements
Open a terminal in the root of the `SURGE-SNAKE` project and install the dependencies:
```bash
pip install -r requirements.txt
```
*(This installs `dynamixel-sdk` and other necessary libraries).*

---

## 4. Running the Feedback Test

To ensure everything is working and to calibrate your obstacle avoidance thresholds, run the motor feedback test script.

1. Open `tests/test_motor_feedback.py` in your code editor.
2. Verify the configuration at the top of the file:
   - Make sure `DXL_ID = 1` matches your motor's ID (brand new motors default to ID 1).
   - Ensure `DEVICENAME` is set to your COM port (e.g., `'COM3'`).
3. Run the script:
   ```bash
   python tests/test_motor_feedback.py
   ```

### What to Expect:
- The motor will enable its torque and stiffen up, holding its center position.
- Your terminal will print a continuous stream of Position, Velocity, and Current (mA).
- **The Obstacle Test:** Gently try to force the motor horn to rotate with your fingers. You will see the `Current (mA)` value spike up on your screen. This spike is exactly what the `ObstacleAvoidance` script in `main.py` looks for to detect collisions!

---

## 5. Next Steps

Once the feedback test is successful, you can connect all **10 motors** in a daisy chain. 
*(Note: You will need to use the Dynamixel Wizard 2.0 software to change each motor's ID from 1 to 10 so they don't conflict on the network).*

After setting the IDs, you are ready to run `python main.py` and watch the snake slither!

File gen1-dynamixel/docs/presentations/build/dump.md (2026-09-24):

<!-- Slide number: 1 -->


INSTITUTION

GROUP CODE · SURGE 090
Indian Institute of Technology, Delhi
PROJECT GUIDE
Progress Review (Design & Development)
Professor Amartansh Dubey
Smart Snake Robot
with Dynamixel Smart Servo Motors



Shashank Jangir
Bhavesh Bansiwal
Mahima Chotiya

ENTRY NO.
ENTRY NO.
ENTRY NO.
2024EE11048
2024ME10487
2024ME11187
PROJECT REPOSITORY
https://github.com/shashankjangir/SurGe-090-Smart-snake-robot

### Notes:
Title slide for the 25% progress review of the Smart Snake Robot project, Group SURGE 090. Introduce the team and milestone scope.

<!-- Slide number: 2 -->
ACTUATOR SELECTION STUDY
Why Dynamixel Motors?
OPTIONS COMPARED

| Criterion | Conventional Servo | Dynamixel Smart Servo |
| --- | --- | --- |
| Communication | Individual signal wire per motor | Daisy-chain communication |
| Wiring Complexity | High | Low |
| Feedback | Not available | Position, load, temperature, voltage feedback |
| Controller | External controller required | Built-in controller |
| Scalability | Difficult for many joints | Designed for multi-joint robots |
| Precision | Moderate | High |
| Robotics Applications | Hobby projects | Research and industrial robotics |
THE REQUIREMENT
A snake robot drives many joints at once. The actuator must deliver:
Precise position control
Simple wiring architecture
Scalability for multiple joints
Reliable communication
Real-time feedback
Compact size & sufficient torque





<!-- Slide number: 3 -->
ARCHITECTURE & DECISION
Daisy-Chain Architecture & Final Selection

Conventional Servo — Separate Wiring

Dynamixel — Daisy-Chain

Servo 1

Controller
Servo 2

Ctrl
M1
M2
M3
M4

Servo 3

Servo 4

Every motor needs its own signal wire back to the controller.
One cable carries power and data to every joint in sequence.

KEY LEARNINGS
FINAL SELECTED ACTUATOR
Dynamixel XL330 Series
Daisy-chain wiring sharply cuts cabling and assembly effort.
A controller built into every motor simplifies integration.
Real-time feedback enables future closed-loop control.
Compact form factor suits modular robot segments.
High precision and smart control fit advanced robotics.
Chosen for its smart serial communication, full-state feedback, compact form factor and effortless multi-joint scaling — the right fit for a multi-segment snake robot.

<!-- Slide number: 4 -->
GOALS & EXPECTED OUTCOMES
What This Project Sets Out to Build

01
02
03






Modular Architecture
Dynamixel Actuators
Raspberry Pi Control
A repeatable segment-based mechanical design.
Integrate smart servos with daisy-chained control.
A single-board-computer control system.

04
05
06






Locomotion Algorithms
Sensor Integration
Scalable Platform
Implement serpentine and gait-based motion.
Add sensing for future intelligent navigation.
Keep it maintainable and easy to extend.

### Notes:
Six concrete goals across mechanics, actuation, computing, control, sensing and scalability. These map to the timeline phases.

<!-- Slide number: 5 -->
WORK COMPLETED SO FAR
Quarter-One Progress Summary

COMPLETED TASKS
OVERALL COMPLETION(till now)

Literature review & project understanding

Raspberry Pi setup & configuration
25 %





Hardware selection & BOM preparation

Wi-Fi connectivity testing on the Pi





CAD design of snake-robot segment

Basic Raspberry Pi lab projects executed




Phase 1 complete · Phase 2 underway

Assembly sized to Dynamixel XL330 dims

GitHub repository created & maintained

10
2
1




Tasks done
Segments printed
Pi configured

3D printing of two prototype segments

Procurement process initiated





### Notes:
About a quarter done: ten tasks closed across research, mechanical design, fabrication and the compute platform.

<!-- Slide number: 6 -->
SYSTEM ARCHITECTURE

Conceptual Block Diagram
Architecture finalized    ·    Implementation in progress
FUTURE INTEGRATION

Power Supply

IMU / Force Sensors

Camera Module

Raspberry Pi 5  [Central Controller]

Control Algorithms

Wireless Control Module

Communication Layer  (U2D2 / UART)

Dynamixel Motor Network

Robot Segments  (10 × servo joints)
LEGEND
Implemented

In Progress

Planned Future Work

Current Implementation Status
Raspberry Pi 5 configured and tested
Mechanical segments fabricated

Communication architecture defined
Dynamixel integration pending hardware

### Notes:
Controller at the centre. Solid cyan = implemented/in progress; dashed amber (sensors, camera) = designed-in but scheduled for a later phase.

<!-- Slide number: 7 -->


ASSEMBLY FLOW
③ Full Assembly
Motor → Segment Parts → Full Chain Assembly
CAD DESIGN DEVELOPMENT
A Segment Designed Around the Motor
The CAD model is built to the exact dimensions of the Dynamixel XL330-M288 servo, using a modular, segment-based architecture focused on manufacturability and scalability.



The image depicts a simple, sturdy, black, rectangular wooden shelving unit with a rectangular shelf in the middle. AI-generated content may be incorrect.

The image depicts a simple, grey, rectangular, flat-sided, metallic-looking panel or bracket, likely with some sort of mechanical attachment or mounting hardware visible, placed on a plain, light-colored background. AI-generated content may be incorrect.

DESIGN CONSIDERATIONS

The image depicts a gray, rectangular frame with an open, hinged structure, likely part of a larger assembly.

Motor mounting  — Precise seats for XL330 servo bodies.



The image depicts a simple, abstract representation of a zigzag pattern or a wave-like structure, rendered in a monochromatic, minimalistic style. AI-generated content may be incorrect.

Structural rigidity  — Stiff frame to resist motion loads.



Cable routing  — Clean daisy-chain channels for wiring.



Electronics ready  — Space reserved for future boards.



① Motor
② Segment Parts
③ Full Assembly

### Notes:
CAD modelled to real XL330 dimensions so printed parts mate with the actual servos. Replace the placeholder with CAD screenshots.

<!-- Slide number: 8 -->
PROTOTYPE FABRICATION
From Model to Printed Hardware

FABRICATION STATUS

The image shows a white, rectangular piece of furniture, possibly a desk or shelf, resting on a patterned carpet with a few scattered fabric scraps nearby.


Two prototype segments 3D printed
DONE


Both segments produced from the CAD model.
PRINTED SEGMENT — PHOTO 1

Initial dimensional verification done
DONE
Insert photo of the first 3D-printed segment


Printed parts measured against design specs.

The image shows a white, rectangular plastic structure lying flat on a patterned carpeted floor. AI-generated content may be incorrect.

Physical validation of CAD initiated
NEXT


Checking fit, tolerances and assembly.



Preparing for motor-integration tests
NEXT

PRINTED SEGMENT — PHOTO 2


Next: seat XL330 servos into segments.
Insert photo of the second segment / assembly

### Notes:
Two segments printed and measured, validating the CAD. Next step is servo integration. Drop prototype photos on the left.

<!-- Slide number: 9 -->
RASPBERRY PI LEARNING & DEVELOPMENT

Standing Up the Compute Platform
Development Environment Setup

PROGRESS MILESTONES

The image shows a schematic diagram of the Raspberry Pi GPIO pinout, detailing the connections between various pins and components such as power, ground, and communication interfaces. AI-generated content may be incorrect.

The image shows a schematic diagram of the Raspberry Pi GPIO pinout, detailing the connections between various pins and components such as power, ground, and communication interfaces. AI-generated content may be incorrect.
Raspberry Pi 5 received & configured





Raspberry Pi OS installation completed





Raspberry Pi OS Desktop
GPIO / Python Testing
Wi-Fi connectivity established





The image shows a Windows command prompt window, with a user logged into a remote Linux system via SSH, navigating through directories and listing files on a desktop. AI-generated content may be incorrect.

The image shows a purple rectangular device, presumably a Raspberry Pi E, with four black USB ports, placed on a wooden surface.

SSH & remote access explored





Basic GPIO & intro projects performed




SSH Remote Access
System Configuration

Raspberry Pi Platform Successfully Configured and Tested

Linux environment & Python familiarity





### Notes:
Control computer is live: OS installed, networked, remotely accessible, exercised with intro GPIO and Python. De-risks software before motors arrive.

<!-- Slide number: 10 -->

HARDWARE PROCUREMENT & RESOURCE AVAILABILITY
Hardware Procurement & Resource Availability

Hardware Strategy: Raspberry Pi 4 was planned in the BOM; however, a Raspberry Pi 5 was already available in the laboratory, enabling immediate software development and testing without waiting for delivery. To accelerate development, the team utilised the laboratory Raspberry Pi 5 platform while the ordered components remain under procurement.

AVAILABLE & IN USE
ORDERED — AWAITING DELIVERY
COMPLETED PREPARATORY WORK

Raspberry Pi 5 (Laboratory Resource)
Raspberry Pi Starter Kit
Raspberry Pi OS Environment
GitHub Repository
3D Printed Prototype Segments
Dynamixel XL330 Smart Servo Motors
U2D2 Communication Interface
U2D2 Power Hub Board
Dynamixel Communication Cables
5V Power Supply
ESP32 Development Board
Hardware selection finalised
Bill of Materials prepared
CAD model completed
Segment fabrication initiated
Software environment configured
DEVELOPMENT PROGRESS

✓

✓

✓

✓

✓

⏳

→

Component
Selection
Procurement
Initiated
CAD
Design
Prototype
Printing
RPi
Learning
Motor
Integration
Locomotion
Testing
Awaiting HW
Upcoming

★
Key Achievement: Although the primary Dynamixel hardware has not yet arrived, the team has successfully utilised available laboratory resources to complete design, fabrication, documentation, and software preparation activities, ensuring project progress is maintained.

### Notes:
Live BOM from the purchasing sheet. Compute hardware in hand; actuation and power chain ordered. Total approx Rs 33,760.

<!-- Slide number: 11 -->

REPOSITORY & DOCUMENTATION
Version Control From Day One

GITHUB REPOSITORY SCREENSHOTS

Locomotion set too 2D forward sine curve movement. AI-generated content may be incorrect.
Repository created
Central home for the whole project.

1

Version control established
Tracked, reversible change history.

2

CAD files uploaded
Design source committed to the repo.

3

GitHub repository — project root & structure

The image shows a collection of text documents and files related to Raspberry Pi setup and testing, including installation guides, hardware documentation, and various scripts and manuals. AI-generated content may be incorrect.

Design iterations documented
Every revision captured in commits.

step AI-generated content may be incorrect.

4

Progress tracking in place
Milestones and issues logged.

5
Commit history — tracked iterations & uploads

Team collaboration workflow
Shared branches and pull requests.

6
✓ All milestones tracked in GitHub

### Notes:
The repo is the single source of truth — CAD, docs, tracked iterations — with a collaboration workflow already running.

<!-- Slide number: 12 -->
PROJECT TIMELINE
Eight Phases · Currently at 25%

PHASE 1
PHASE 3
PHASE 5
PHASE 7
Research & Design
Mechanical Assembly
Control Algorithms
Testing & Optimisation
Completed
Up next

1

2

3

4

5

6

7

8

PHASE 2
PHASE 4
PHASE 6
PHASE 8
Hardware Procurement
Motor Integration
Sensor Integration
Final Demonstration
In progress

WE ARE HERE

### Notes:
Eight-phase plan: Phase 1 complete, Phase 2 active, Phase 3 next — about 25%. Phases 4-8 cover integration, control, sensing, testing, demo.

<!-- Slide number: 13 -->
CURRENT ACHIEVEMENTS
Concrete Wins in Quarter One












Architecture finalized
CAD design completed
Prototype fabrication started
System block diagram locked.
Segment modelled to motor specs.
Two segments printed & checked.












Pi environment established
GitHub workflow operational
Procurement initiated
OS, network and tooling ready.
Version control and docs live.
Core compute received; rest ordered.

### Notes:
Six headline achievements: design, fabrication, compute, tooling and procurement all moving — a working foundation.

<!-- Slide number: 14 -->

SIMULATION & VALIDATION

Simulation-Based Validation of Control Architecture

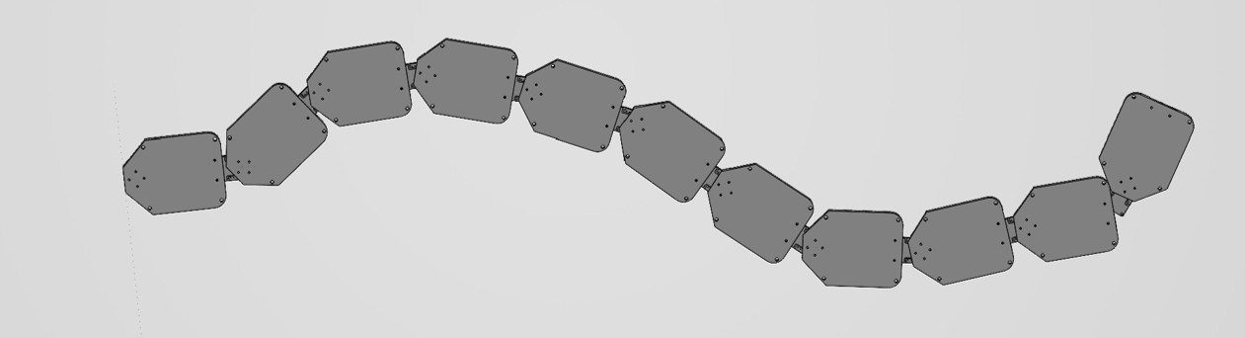
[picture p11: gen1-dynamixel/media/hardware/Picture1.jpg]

SIMULATION OBJECTIVE
A virtual testing platform to validate the control architecture before Dynamixel actuators and communication hardware arrive — enabling software development, algorithm verification, and sensor integration in parallel with procurement.
COMPONENTS SIMULATED

Controller

Sensors

Display

Actuators
Controller
Sensors
Display
Actuators
ESP32 · 5-Servo joint network · MPU6050 IMU · HC-SR04 ultrasonic · SSD1306 OLED · control & communication framework
FUNCTIONAL VALIDATION COMPLETED
Multi-joint servo coordination
Travelling-wave serpentine gait generation
Obstacle detection via ultrasonic sensing
IMU integration for orientation feedback
OLED-based system status monitoring
Sensor–controller–actuator communication
ENGINEERING BENEFITS
Reduced dependence on hardware delivery timelines
Enabled early software debugging & control-architecture verification
Established migration path to Raspberry Pi 5 + Dynamixel XL330, reducing integration risk
Wokwi-based simulation environment developed to validate locomotion control, sensor integration, and communication architecture before physical Dynamixel hardware arrival.
KEY OUTCOME  A complete software-validation framework was developed, allowing locomotion, sensing, and control workflows to be tested before physical robot assembly.

<!-- Slide number: 15 -->

FUTURE WORK & DEVELOPMENT ROADMAP

Planned Activities for the Next Development Phase

Hardware Arrival

Mechanical Assembly

Communication Setup

Locomotion Development

Sensor Integration

Testing & Optimization

1

2

3

4

5

6

Hardware arrival

Mechanical assembly

Communication setup

Locomotion development

Sensor integration

Testing and optimization
Receive Dynamixel XL330 motors
Receive U2D2 interface
Verify purchased components
Assemble complete snake body
Install Dynamixel actuators
Route communication cables
Configure motor IDs
Establish serial communication
Validate daisy-chain architecture
Port simulation code to Pi 5
Implement serpentine locomotion
Synchronize multi-joint movement
Integrate MPU6050 IMU
Integrate obstacle detection
Implement feedback control
Motion performance testing
Power & reliability analysis
System optimization
Completed phase
Ongoing work
Future milestone

EXPECTED DELIVERABLES
TARGET FOR NEXT REVIEW
Fully assembled snake robot
Dynamixel-based locomotion
Sensor-assisted navigation
Integrated Raspberry Pi 5 control system
Demonstration-ready prototype
Final SURGE project showcase
Complete hardware integration
Demonstrate basic snake locomotion
Validate communication architecture
Validate sensing framework

Goal: ~60–70% project completion

<!-- Slide number: 16 -->



WHAT CHANGED SINCE THIS REVIEW
Generation 2 — Corrections & Cause
Slides 1–15 are unchanged from the 25% review. This slide records what has since been superseded.
| SLIDE | THAT DECK SAID | TODAY | WHY |
| --- | --- | --- | --- |
| 10 | XL330 · U2D2 · Power Hub — “ORDERED, AWAITING DELIVERY” | Order cancelled. 10× ST3215 + Waveshare ESP32 driver in hand | Part unobtainable in India |
| 12 | “Eight Phases · Currently at 25%” | Phase 3 — Fabrication & Assembly | Eight weeks of Gen 2 work since |
| 13 | “Prototype fabrication started” | Gen 1 segments printed; Gen 2 v6 not yet printed | Design of record changed |
| 15 | Roadmap step 1 — “Receive Dynamixel XL330 motors” | Superseded — see slide 29 | Different motors received |

Constraint
Six-week stall
Re-architecture

WHAT HAPPENED
IMPACT
COMMIT a32b675 · 2026-08-20
2 of 10 XL330 received, then the part vanished
Control stack written against absent hardware
“No dynamixel in the market. So switched to Servos”
WHAT IT BOUGHT   5.7× joint torque (0.52 → 2.94 N·m)  ·  a 12 V rail  ·  sourceable in India  —  consequences of the switch, not its reason. Torque budget: slide 23.

### Notes:
Open by saying the deck up to this point is unchanged from the 25 percent review and is being left that way deliberately - those slides are a record of what we believed then, not a claim about now. Then walk the register top to bottom. It takes about forty seconds and it pre-empts every 'but slide 10 says' interruption in the second half. Say the honest version of the pivot out loud: this was a procurement failure, not an engineering preference, and a re-architecture under a supply constraint is a legitimate result. The follow-up question a reviewer asks is 'where is your torque budget' - it is slide 23, and it did not exist at the 25 percent review.

<!-- Slide number: 17 -->
ACTUATOR RE-SELECTION
From XL330 to Waveshare ST3215
XL330 VS ST3215 — AS SELECTED

| Criterion | Dynamixel XL330 (Gen 1) | Waveshare ST3215 (Gen 2) |
| --- | --- | --- |
| Stall torque | 0.52 N·m | 2.94 N·m — 5.7× higher |
| Voltage rail | 5 V | 6.0–12.6 V |
| Stall current | 0.35 A | 2.7 A @ 12 V |
| Encoder | 12-bit absolute | 12-bit absolute, 0–4095 |
| Bus protocol | Dynamixel 2.0, 1 Mbps | Feetech STS, 1 Mbps half-duplex |
| Driver hardware | U2D2 + Power Hub + MCU | Waveshare driver, ESP32 onboard |
| Availability in India | Unobtainable | In stock — 10 units held |
THE CONSTRAINT
The Gen 1 trade study was sound and its conclusion still holds: a snake robot needs smart serial bus servos. Only the vendor changed. XL330 became unobtainable in the Indian market after 2 of 10 units were received.
Precise absolute position control
Single-cable daisy-chain wiring
Per-joint load and current feedback
Built-in controller, no external driver per joint
Scalable to 10 coordinated joints
Procurable in India, in quantity





### Notes:
The Gen 1 trade study is not invalidated - its conclusion was smart bus servos, and that is what we still run. Only the vendor changed, and it changed for supply reasons, not engineering ones. The torque column is the favourable consequence: 5.7x more joint torque at the same joint count. The voltage change from 5 V to 12 V is what forced the power architecture rework on slide 24.

<!-- Slide number: 18 -->
GEN 1 → GEN 2 ARCHITECTURE

From Tethered Pi Control to Onboard ESP32
Control moved onto the robot    ·    Pi 5 relegated to base station    ·    Link is now wireless
OFF-ROBOT & PLANNED

3S LiPo 1800 mAh   (11.1 – 12.6 V)

MPU6050 IMU  (I²C 21 / 22)

ESP32 Camera  (planned)

Waveshare Driver + ESP32   [Robot Master]

Gait CPG runs onboard

ESP-NOW → ESP32 #2 → Pi 5

Feetech STS Bus   (1 Mbps, half-duplex)

10 × Waveshare ST3215 Servos

Robot Segments   (10 × servo joints)
LEGEND
Implemented

In Progress

Planned Future Work

Generation 2 Implementation Status
All firmware targets written and building
v6 segments not yet printed

Servo IDs not yet assigned — all ship as ID 1
ESP-NOW link not yet exercised on hardware

### Notes:
The single most important change is where control lives. In Generation 1 the Raspberry Pi was the controller and sat on the robot, tethered over USB to a U2D2. In Generation 2 the ESP32 on the Waveshare driver is the master, the Pi 5 moved off the robot entirely, and the link between them is ESP-NOW rather than a cable. That is what makes untethered operation possible. Compare this against the Generation 1 block diagram on slide 6 - the shape of the system is genuinely different, not just re-labelled.

<!-- Slide number: 19 -->

ONBOARD FIRMWARE STACK
ESP32 Firmware — Four Targets, One Bus

Firmware Strategy: the Waveshare driver's onboard ESP32 is the robot master and owns the servo bus; a second ESP32 at the base station receives telemetry over ESP-NOW and forwards it to the Pi 5 by USB serial. Bench and field firmware are mutually exclusive on the driver board — one is flashed at a time.

ROBOT ESP32 — FIELD
BASE STATION ESP32 #2
BENCH & BRING-UP TOOLS

robot_esp32 — gait CPG, 10-DOF
MPU6050 on I2C GPIO 21 / 22
Current-stall obstacle FSM
ESP-NOW telemetry transmit
base_esp32 — ESP-NOW receive
USB serial to Pi 5 @ 115200
base_station.py logs telemetry
spin_all — broadcast smoke test
assign_ids — one servo at a time
usb_servo_bridge — Python stack
PlatformIO, one env per sketch
FIRMWARE BRING-UP SEQUENCE

✓

✓

✓

⏳

→

→

→

Firmware
written
PlatformIO
builds
Broadcast
smoke test
ID
assignment
Bus
verification
Gait on
hardware
ESP-NOW
telemetry
Upcoming
Upcoming

★
Key Achievement: all five firmware targets are written and compile clean under PlatformIO, and the broadcast smoke test drives all ten servos before any ID has been assigned — so the control stack was validated without waiting on bring-up.

### Notes:
Three ESP32s in total, two on the robot and one at the base. The important design point is that video and telemetry are separate radio links: ESP-NOW carries telemetry, ordinary WiFi will carry camera video. Do not try to push video through ESP-NOW - the payload cap is 250 bytes. The bring-up rail is honest: we are at ID assignment, not past it.

<!-- Slide number: 20 -->
BUS PROTOCOL
Feetech STS Control Table & Packet Format
CONTROL TABLE — IMPLEMENTED

| Register | Addr | Width and meaning |
| --- | --- | --- |
| ID | 5 | 1 byte, EEPROM — factory default 1 |
| TORQUE\_ENABLE | 40 | 1 byte 0 = off, 1 = on |
| GOAL\_POSITION | 42 | 2 bytes, little-endian, 0–4095 |
| GOAL\_SPEED | 46 | 2 bytes, steps per second |
| LOCK | 55 | 1 byte, EEPROM write gate |
| PRESENT\_POSITION | 56 | 2 bytes, centre = 2048 |
| PRESENT\_CURRENT | 69 | 2 bytes, bit15 = sign, 6.5 mA/count |
PACKET FORMAT
All ten servos share one half-duplex TTL line at 1 Mbps. Every packet is addressed to a single ID, or to broadcast ID 0xFE, which every servo acts on and none replies to — the only safe way to drive the bus before IDs are assigned.
Header  0xFF 0xFF
ID  1–253, or 0xFE broadcast
Length  parameters + 2
Instruction  0x03 = WRITE, 0x02 = READ
Parameters  address, then data bytes
Checksum  bitwise NOT of the byte sum
Multi-byte fields are little-endian





### Notes:
This is the whole interface. Two register facts matter downstream: GOAL_POSITION is little-endian and 0-4095 with centre 2048, which is a 4x scale difference from the SC-series servos the Waveshare board ships configured for; and PRESENT_CURRENT at address 69 is how we detect a stall, at 6.5 mA per count with the sign in bit 15. The 1200 mA threshold in robot_config.py is still a placeholder and needs calibrating against a real stall.

<!-- Slide number: 21 -->

CAD EVOLUTION
Segment Design v4 → v5 → v6

Design Strategy: the segment is a parametric CadQuery model, not a hand-drawn solid, so every dimension traces to a named constant and the model refuses to export if its own assumptions stop holding. v6 is the design of record; its three fixes were found by measuring the earlier versions rather than looking at them.

V4 — BASELINE
V5 — SUPERSEDED
V6 — DESIGN OF RECORD

First parametric segment
58 mm joint-to-joint pitch
Ground contact never measured
Superseded, still printable
Widened yoke rectangle
Early sidewall bug fixed
Shares v4's bounding box
Dimensional error — do not print
Belly scales now touch ground
Scales reoriented for undulation
Positive M2 motor retention
Self-check asserts all three
FABRICATION PIPELINE

✓

✓

⏳

→

→

→

→

Parametric
model
Self-check
passes
Probe
ST3215 STEP
Print one
segment
Measure
friction
Print
remaining 10
Chain
assembly
Upcoming
Upcoming

★
Key Achievement: v6 caught three defects that v4 and v5 shared — the bottom plate sat 0.45 mm below the belly scales so 94% of ground contact was the one surface never meant to touch; the scales resisted the wrong axis for lateral undulation; and the motor had no positive retention at all.

### Notes:
The headline is that these defects were found by measurement, not by inspection - the model enumerates every face at minimum z and asserts which ones they are. Print v6, not v4 and definitely not v5. The friction measurement in step 5 is the real unknown: every locomotion claim in this deck assumes anisotropic belly friction that has never been measured on a printed part.

<!-- Slide number: 22 -->
STRUCTURE & LOAD PATH
v6 Load Path & Positive Motor Retention

v4 / v5 — Motor Lifts Straight Out

v6 — Captured in a Closed Cradle

Slip-fit 0.4 mm

Horn
Open at top

Horn
M2
M2
M2
M2

Lightening windows

~1 mm rear wall

The motor sits in an open pocket with no fastener. Nothing resists it lifting out.
Four M2 screws capture the motor against a closed cradle wall.

LOAD PATH
RETENTION — RESOLVED IN V6
Four M2 screws through a closed cradle
Horn face transfers joint torque to the next segment
F623ZZ flange bearing on the horn-opposite side
Bearing carries radial load off the motor shaft
14 mm bolt circle, 4 × M2 blind holes each face
Closed cradle wall reacts motor reaction torque
v4 and v5 relied on an interference fit alone. Under repeated gait loading that is a slow failure: the pocket wears, the motor rocks, and joint backlash grows. v6 adds positive fastening and restores the sidewall the lightening windows removed.

### Notes:
The load path point is that the motor shaft should not be carrying radial load - the F623ZZ bearing on the opposite face does that, and the horn only transfers torque. The retention fix matters more than it sounds: an interference fit that loosens turns into joint backlash, and backlash in a 10-joint chain compounds into a gait that will not track. This was found by measuring the pocket, not by looking at it.

<!-- Slide number: 23 -->
FRICTION, KEELS & TORQUE
Why v6 Can Actually Move — Friction & Torque Budget

v4 / v5 — Scales Never Touched Ground

v6 — Keels Carry the Robot

Plate at −3.45 mm

Belly
Scales at −3.00 mm

Belly
Grip
Slide
Grip
Slide

Plate 1006 mm²

Scales 66 mm²

The plate hung 0.45 mm below the scales — 94% of ground contact was the one surface never meant to touch.
Scales swept along the body: grip across it, slide along it — the asymmetry lateral undulation requires.

TORQUE BUDGET
THE REMAINING UNKNOWN
Anisotropic friction ratio is unmeasured
ST3215 stall torque 2.94 N·m at 12 V
XL330 was 0.52 N·m — 5.7× less
10 joints, 58 mm pitch, ~580 mm body
Head pod adds ≈ 0.02 N·m — under 1% of budget
Torque is no longer the binding constraint
Every locomotion claim in this deck assumes the belly grips across the body and slides along it. That ratio has never been measured on a printed part. Printing one v6 segment and measuring fore/aft versus lateral friction is the single highest-value next experiment.

### Notes:
Two halves. The torque half is settled - 5.7 times more joint torque than Generation 1, and the head pod barely registers against it, so torque stopped being the limiting factor the moment we switched actuators. The friction half is not settled and I want to be explicit about that. A snake robot moves by having different friction across the body than along it. v4 and v5 got that backwards and also never touched the ground with the feature that was supposed to do it. v6 fixes both in CAD, but nobody has put a printed segment on a surface and measured the ratio. Until that happens, the gait is theory.

<!-- Slide number: 24 -->
ELECTRICAL & POWER ARCHITECTURE

Field and Bench Power Paths
Robot rail resolved    ·    No DC conversion needed    ·    Protection hardware outstanding
BENCH PATH (TETHERED)

3S LiPo 1800 mAh   —   20.0 Wh

Mean Well LRS-100-5  (5 V, 20 A)

12 V 2 A supply  —  ID assignment

Inline fuse  +  XT60 loop key   [NOT YET HELD]

≈ 22 min at 4 A

XL6009 boost  —  one servo only

1000 µF bulk capacitor   [NOT YET HELD]

Waveshare Driver VIN   (6 – 12 V)

10 × ST3215   —   27 A worst-case stall
LEGEND
Implemented

In Progress

Planned Future Work

Power Status & Open Risks
LiPo sits inside the servo range — no conversion needed
Fuse, BMS and loop key are not yet in inventory

Driver is rated 6–12 V; a full 3S pack is 12.6 V
LiPo C-rating unverified — sets the real current ceiling

### Notes:
The resolved part is the robot rail: a 3S pack sits inside the ST3215's 6.0 to 12.6 volt window, so it feeds the driver directly with no buck or boost anywhere in the path. That removes the whole conversion problem Generation 1 had at 5 volts. Two things are not resolved and both belong on the record. First, Waveshare rates this board 6 to 12 volts, and a fully charged 3S pack is 12.6 - so we are 0.6 volts over spec at the top of every charge cycle. Second, none of the three protection parts are held yet. The 27 amp figure is worst-case all-joints-stalled, not normal draw, but it is what sizes the fuse.

<!-- Slide number: 25 -->
SAFETY ARCHITECTURE & CRITICAL GAPS
Five Protection Parts the Robot Does Not Yet Have












Inline fuse — MISSING
Loop-key disconnect — MISSING
LiPo alarm / BMS — MISSING
Nothing limits fault current on a 27 A-capable pack.
No safe way to isolate the battery from the bus.
No cell-level undervoltage protection below 3.0 V.












Bulk capacitor — MISSING
Balance charger & bag — MISSING
Current-stall limit — IN FIRMWARE
Servo inrush transients reach the driver unsuppressed.
No safe charge, balance or storage path for the pack.
Software torque cap works, but is not a fuse.

### Notes:
This is the slide I would rather not need. Five of the six cards are amber and they are all cheap - roughly 3600 rupees for the whole row. The reason it is on the deck rather than buried in a spreadsheet is that a 3S lithium polymer pack capable of 27 amps, with no fuse, no cell monitoring and no disconnect, is the one genuinely hazardous thing in this project. The sixth card is deliberate: the firmware current limit is real and it works, but software cannot protect against a short circuit. Nothing goes on the LiPo until the first three are fitted.

<!-- Slide number: 26 -->
GAIT & OBSTACLE RESPONSE
Gait Generation and the Evasion State Machine

Lateral Undulation — Travelling Wave

Evasion Finite State Machine

Joint 1   φ = 0°

CPG
Joint 2   φ = 72°

FSM
RUN
STALL
BACK
TURN

Joint 3   φ = 144°

Joint 4   φ = 216°

A serpenoid phase offset propagates down the chain at 50 Hz; amplitude 400 ticks ≈ 35°.
A sustained current rise trips STALL; the robot reverses, turns away, then resumes.

GAIT PARAMETERS
OBSTACLE DETECTION
Proprioceptive — no external sensor
Control loop 50 Hz
Amplitude 400 encoder ticks ≈ 35°
Phase offset 72° per joint, 10 joints
Goal position written as a sync payload
Gait continues if the IMU is absent
Collision is inferred from PRESENT_CURRENT at address 69 rather than a rangefinder. The threshold is still a placeholder at 1200 mA and must be calibrated against a measured free-run and stall current before it can be trusted.

### Notes:
The gait is a central pattern generator - a travelling sine wave with a fixed phase offset per joint, which is the standard lateral undulation formulation. The part worth drawing attention to is obstacle detection: there is no ultrasonic sensor and no rangefinder in the loop. The robot notices an obstacle because a joint draws more current than it should, which is proprioception rather than exteroception. That is elegant and it costs nothing in hardware, but the threshold is a guess until we measure a real stall on a real segment.

<!-- Slide number: 27 -->
VERIFICATION & MOCK-MODE RESULTS
What Has Been Proven Without Hardware












v6 CAD self-check
Mock mode — SURGE_MOCK=1
Wokwi simulation
Model refuses to export if its assumptions break.
Full gait stack runs with no servos attached.
ESP32, servos, IMU and display validated virtually.












PlatformIO — five targets
Broadcast smoke test
Hardware verification
All firmware environments compile clean.
Ten servos driven before any ID was assigned.
Ping, stall calibration and gait still outstanding.

### Notes:
The honest framing is that this is verification without hardware, which is worth a lot but is not the same as a working robot. The five green cards are real: the CAD model asserts its own ground-contact geometry, the Python stack runs a full gait in mock mode, the simulation covers the electronics, every firmware target builds, and the broadcast test moved all ten servos on the bench. The amber card is the point of the slide - nothing has been calibrated against a real stall current yet, and that is the next measurement.

<!-- Slide number: 28 -->

INVENTORY, BUDGET & PROCUREMENT GAPS
What We Hold, What We Still Need

Budget Position: Gen 1 spend was approximately ₹33,760 of the ₹1,00,000 SURGE grant. Remaining procurement is estimated at ₹10,200 and is almost entirely consumables and safety hardware — the expensive actuator and compute line items are already held.

IN HAND — 9 LINE ITEMS
MISSING — CRITICAL (SAFETY)
MISSING — HIGH PRIORITY

10× Waveshare ST3215 servos
Waveshare driver with ESP32
ESP32 #2, Pi 5 8 GB, MPU6050
3S LiPo 1800 mAh, Mean Well 5 V
Camera Module 3, XL6009 boost
Inline fuse and holder
LiPo alarm / BMS module
XT60 loop-key disconnect
Without these the pack is unsafe
3S balance charger, storage bag
Servo daisy-chain cables ×12
F623ZZ bearings, M2 fasteners
PLA+ filament, TPU belly pads
PROCUREMENT STATUS

✓

✓

✓

⏳

→

→

→

Actuators
received
Compute
received
Power
source held
Safety
parts
Fasteners
& bearings
Filament
& pads
Camera
for ESP32
Upcoming
Upcoming

★
Key Achievement: the actuator blocker that stalled Generation 1 is cleared — all ten servos, the driver board and the power source are in hand. Every remaining gap is a low-cost consumable, not a supply-chain risk.

### Notes:
Be direct about the sunk Gen 1 cost. The favourable point is that Gen 2 needs only consumables and safety parts and the grant covers it comfortably. The critical row is not optional - running a 3S LiPo with no fuse, no BMS and no disconnect is the one genuinely unsafe thing in this project. Verify the ST3215 purchase cost before presenting; the inventory lists them as held but records no price.

<!-- Slide number: 29 -->
ROADMAP
Path to Demonstration — Generation 2
Replaces the Generation 1 roadmap on slide 15, which was written around Dynamixel XL330 delivery and is now obsolete.

PHASE 1
PHASE 3
PHASE 5
PHASE 7
Power Verification
Segment Fabrication
Field Integration
Characterisation
In progress
Planned

1

2

3

4

5

6

7

8

PHASE 2
PHASE 4
PHASE 6
PHASE 8
Servo Bring-Up
Mechanical Assembly
Locomotion Trials
Final Demonstration
Up next

WE ARE HERE

### Notes:
Open by naming slide 15 and saying plainly that it is superseded - do not let the audience find two roadmaps on their own and wonder which one is live. The eight phases here are the actual next steps from the hardware inventory, not a re-skin of the old plan. Phase 1 is where we are: the pack cannot go on the robot until the fuse, loop key and BMS are fitted. Close on phase 3, because it contains the one experiment everything else depends on - printing a v6 segment and measuring whether the belly friction is actually anisotropic. If it is not, the gait does not work and we would rather know that before printing ten more segments. Target for the next review is first translating locomotion on hardware, which is a milestone you can watch rather than a percentage you have to trust.

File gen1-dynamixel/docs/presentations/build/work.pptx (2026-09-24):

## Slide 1

GROUP CODE · SURGE 090

INSTITUTION

Indian Institute of Technology, Delhi

Progress Review (Design & Development)

Smart Snake Robot

with Dynamixel Smart Servo Motors

PROJECT GUIDE

Professor Amartansh Dubey

Shashank Jangir

ENTRY NO.

2024EE11048

Bhavesh Bansiwal

ENTRY NO.

2024ME10487

Mahima Chotiya

ENTRY NO.

2024ME11187

PROJECT REPOSITORY

https://github.com/shashankjangir/SurGe-090-Smart-snake-robot

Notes: Title slide for the 25% progress review of the Smart Snake Robot project, Group SURGE 090. Introduce the team and milestone scope.

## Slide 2

ACTUATOR SELECTION STUDY

Why Dynamixel Motors?

OPTIONS COMPARED

Criterion | Conventional Servo | Dynamixel Smart Servo
Communication | Individual signal wire per motor | Daisy-chain communication
Wiring Complexity | High | Low
Feedback | Not available | Position, load, temperature, voltage feedback
Controller | External controller required | Built-in controller
Scalability | Difficult for many joints | Designed for multi-joint robots
Precision | Moderate | High
Robotics Applications | Hobby projects | Research and industrial robotics

THE REQUIREMENT

A snake robot drives many joints at once. The actuator must deliver:

- Precise position control
- Simple wiring architecture
- Scalability for multiple joints
- Reliable communication
- Real-time feedback
- Compact size & sufficient torque

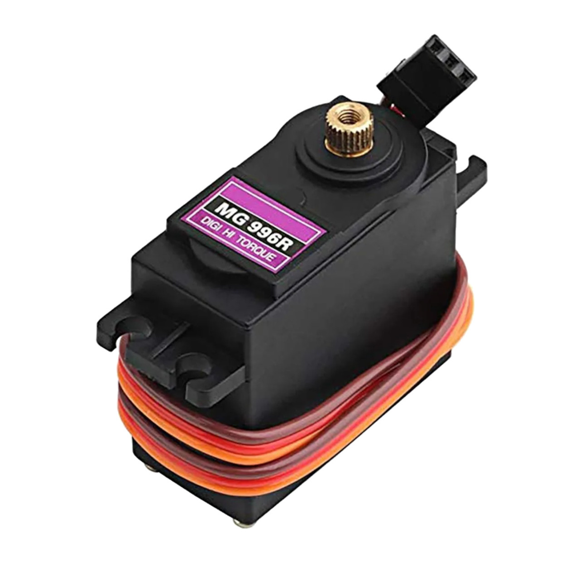
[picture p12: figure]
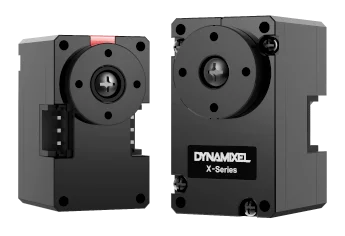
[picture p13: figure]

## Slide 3

ARCHITECTURE & DECISION

Daisy-Chain Architecture & Final Selection

Conventional Servo — Separate Wiring

Every motor needs its own signal wire back to the controller.

Dynamixel — Daisy-Chain

One cable carries power and data to every joint in sequence.

Controller

Servo 1

Servo 2

Servo 3

Ctrl

M1

M2

M3

M4

Servo 4

KEY LEARNINGS

- Daisy-chain wiring sharply cuts cabling and assembly effort.
- A controller built into every motor simplifies integration.
- Real-time feedback enables future closed-loop control.
- Compact form factor suits modular robot segments.
- High precision and smart control fit advanced robotics.

FINAL SELECTED ACTUATOR

Dynamixel XL330 Series

Chosen for its smart serial communication, full-state feedback, compact form factor and effortless multi-joint scaling — the right fit for a multi-segment snake robot.

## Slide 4

GOALS & EXPECTED OUTCOMES

What This Project Sets Out to Build

Modular Architecture

A repeatable segment-based mechanical design.

Dynamixel Actuators

Integrate smart servos with daisy-chained control.

Raspberry Pi Control

A single-board-computer control system.

01

02

03

Locomotion Algorithms

Implement serpentine and gait-based motion.

Sensor Integration

Add sensing for future intelligent navigation.

Scalable Platform

Keep it maintainable and easy to extend.

04

05

06

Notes: Six concrete goals across mechanics, actuation, computing, control, sensing and scalability. These map to the timeline phases.

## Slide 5

WORK COMPLETED SO FAR

Quarter-One Progress Summary

COMPLETED TASKS

OVERALL COMPLETION(till now)

25 %

Phase 1 complete · Phase 2 underway

Literature review & project understanding

Raspberry Pi setup & configuration

Hardware selection & BOM preparation

Wi-Fi connectivity testing on the Pi

CAD design of snake-robot segment

Basic Raspberry Pi lab projects executed

10

Tasks done

2

Segments printed

1

Pi configured

Assembly sized to Dynamixel XL330 dims

GitHub repository created & maintained

3D printing of two prototype segments

Procurement process initiated

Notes: About a quarter done: ten tasks closed across research, mechanical design, fabrication and the compute platform.

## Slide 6

SYSTEM ARCHITECTURE

Conceptual Block Diagram

Architecture finalized · Implementation in progress

FUTURE INTEGRATION

IMU / Force Sensors

Power Supply

Raspberry Pi 5 [Central Controller]

Control Algorithms

Camera Module

Communication Layer (U2D2 / UART)

Wireless Control Module

Dynamixel Motor Network

Robot Segments (10 × servo joints)

LEGEND

Implemented

In Progress

Current Implementation Status

Planned Future Work

Raspberry Pi 5 configured and tested

Communication architecture defined

Mechanical segments fabricated

Dynamixel integration pending hardware

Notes: Controller at the centre. Solid cyan = implemented/in progress; dashed amber (sensors, camera) = designed-in but scheduled for a later phase.

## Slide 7

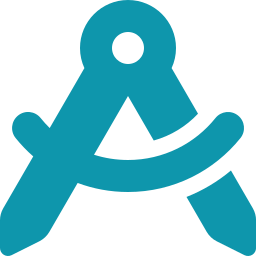
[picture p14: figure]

ASSEMBLY FLOW

Motor → Segment Parts → Full Chain Assembly

③ Full Assembly

CAD DESIGN DEVELOPMENT

A Segment Designed Around the Motor

The CAD model is built to the exact dimensions of the Dynamixel XL330-M288 servo, using a modular, segment-based architecture focused on manufacturability and scalability.

DESIGN CONSIDERATIONS

Motor mounting — Precise seats for XL330 servo bodies.

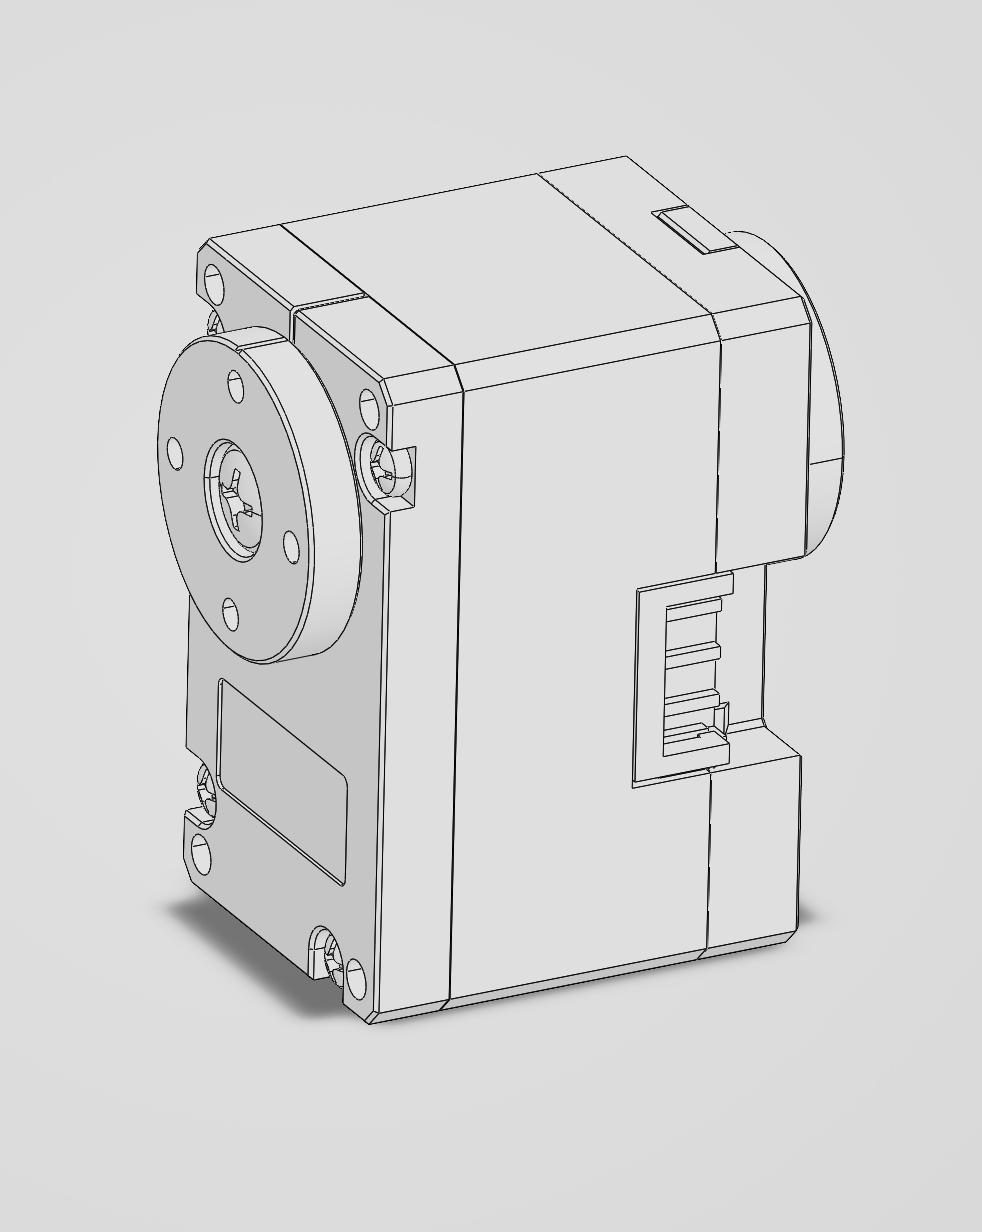
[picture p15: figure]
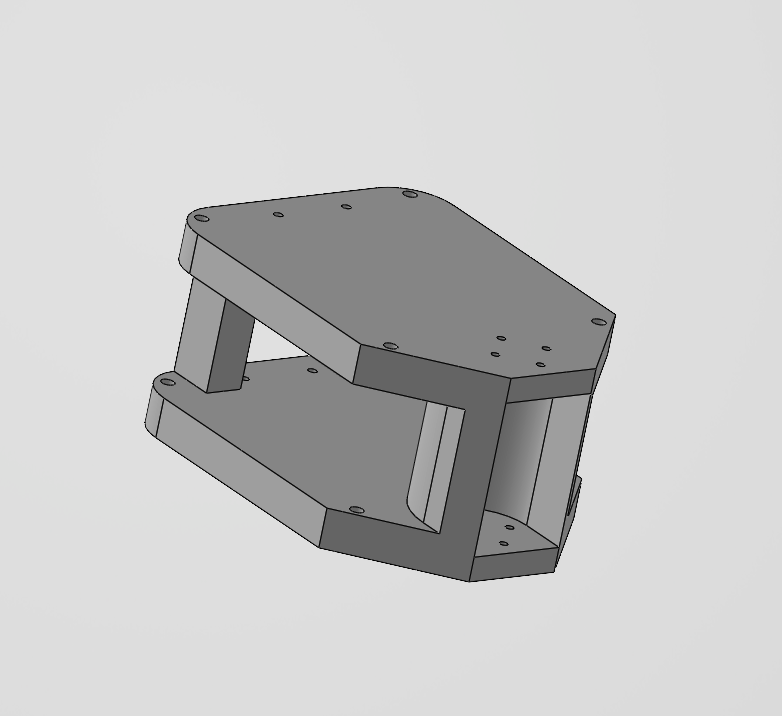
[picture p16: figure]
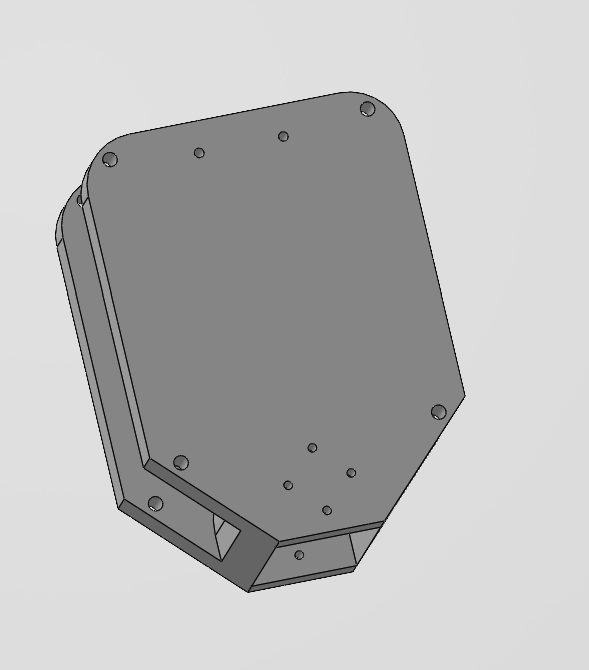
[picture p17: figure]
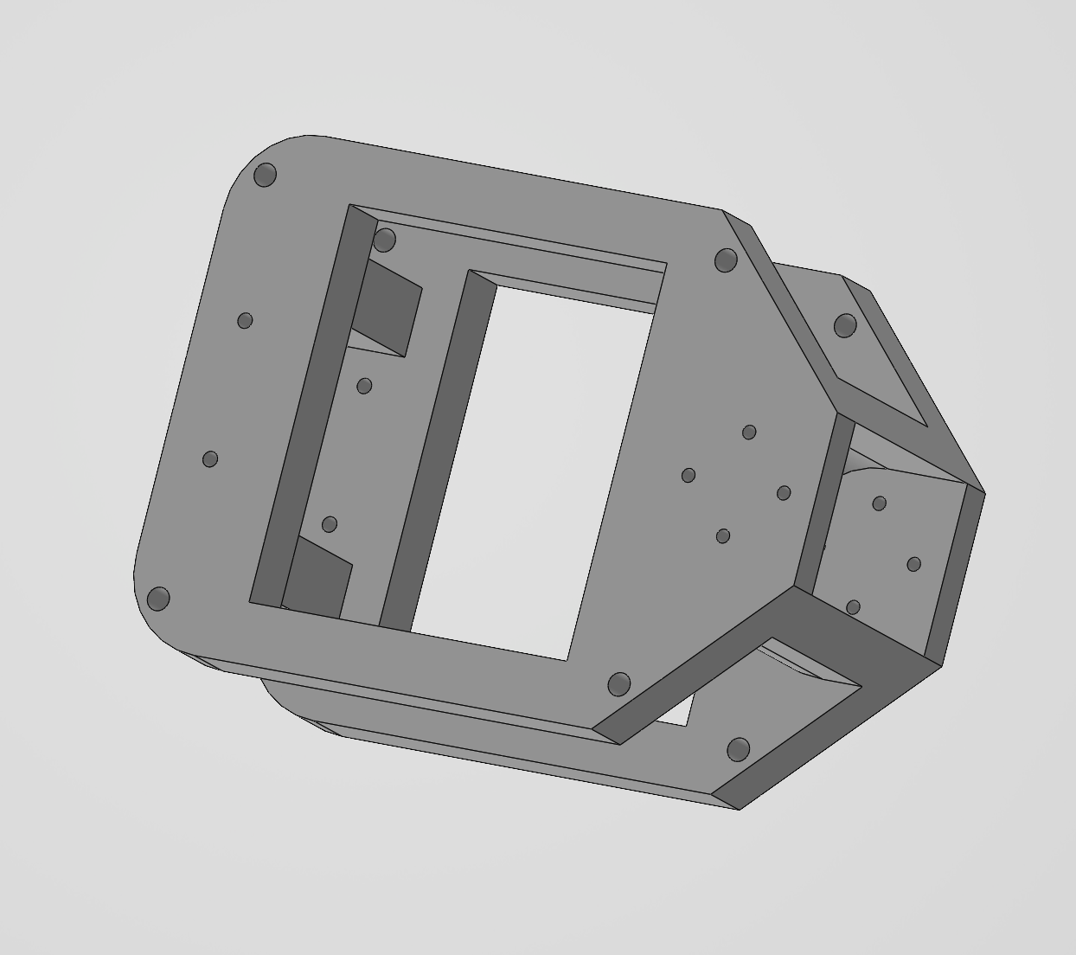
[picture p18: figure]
The image depicts a gray, rectangular frame with an open, hinged structure, likely part of a larger assembly.

Structural rigidity — Stiff frame to resist motion loads.

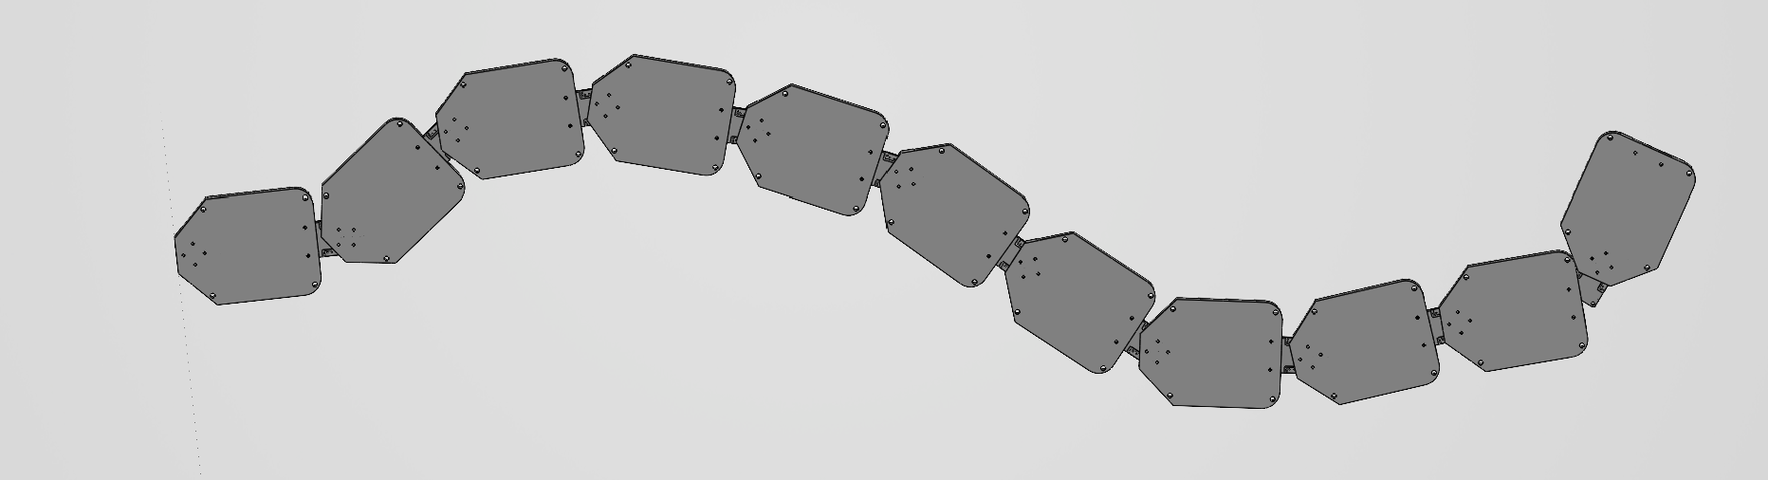
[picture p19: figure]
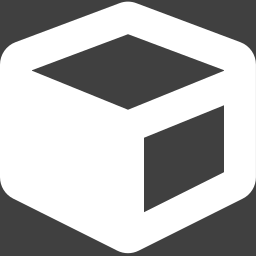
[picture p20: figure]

Cable routing — Clean daisy-chain channels for wiring.

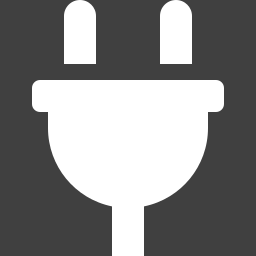
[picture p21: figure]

Electronics ready — Space reserved for future boards.

① Motor

② Segment Parts

③ Full Assembly

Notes: CAD modelled to real XL330 dimensions so printed parts mate with the actual servos. Replace the placeholder with CAD screenshots.

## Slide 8

PROTOTYPE FABRICATION

From Model to Printed Hardware

PRINTED SEGMENT — PHOTO 1

Insert photo of the first 3D-printed segment

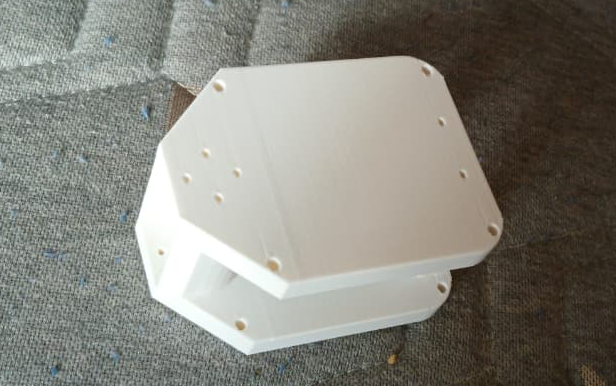
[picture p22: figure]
The image shows a white, rectangular piece of furniture, possibly a desk or shelf, resting on a patterned carpet with a few scattered fabric scraps nearby.

FABRICATION STATUS

Two prototype segments 3D printed

Both segments produced from the CAD model.

DONE

Initial dimensional verification done

Printed parts measured against design specs.

DONE

PRINTED SEGMENT — PHOTO 2

Insert photo of the second segment / assembly

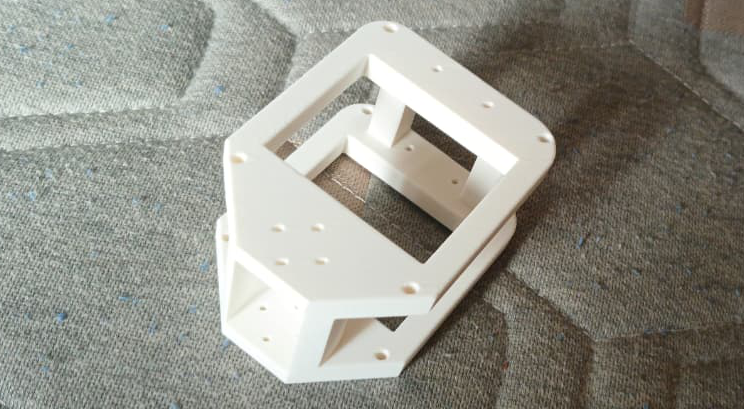
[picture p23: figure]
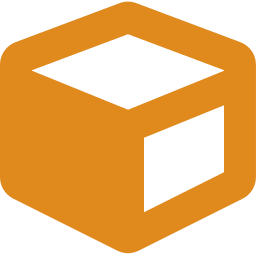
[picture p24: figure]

Physical validation of CAD initiated

Checking fit, tolerances and assembly.

NEXT

Preparing for motor-integration tests

Next: seat XL330 servos into segments.

NEXT

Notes: Two segments printed and measured, validating the CAD. Next step is servo integration. Drop prototype photos on the left.

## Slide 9

RASPBERRY PI LEARNING & DEVELOPMENT

Standing Up the Compute Platform

PROGRESS MILESTONES

Raspberry Pi 5 received & configured

Raspberry Pi OS installation completed

Wi-Fi connectivity established

SSH & remote access explored

Basic GPIO & intro projects performed

Linux environment & Python familiarity

Development Environment Setup

Raspberry Pi OS Desktop

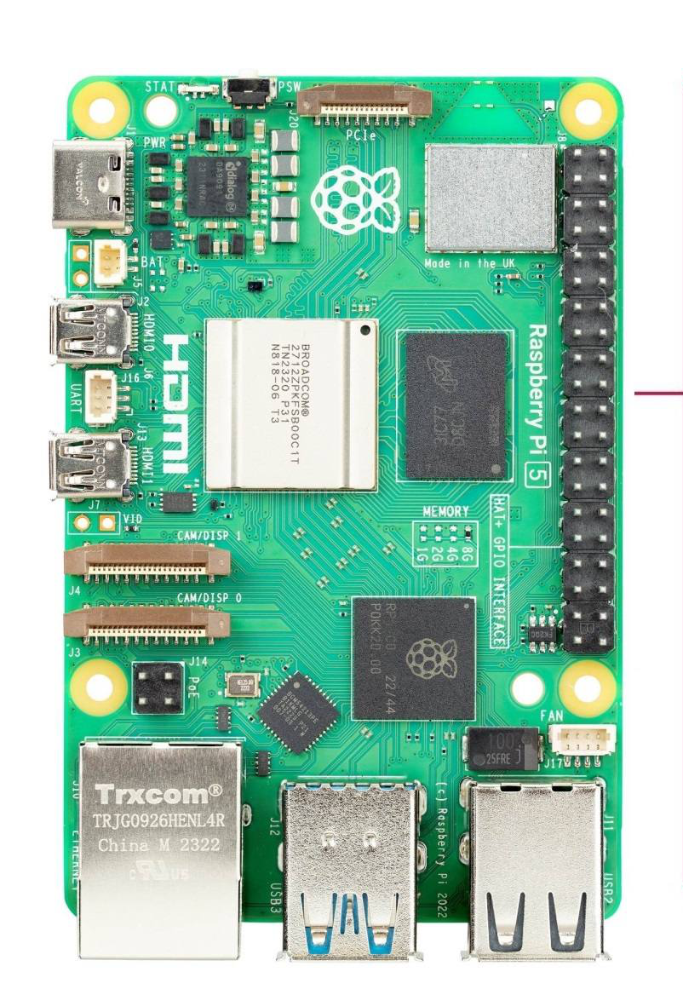
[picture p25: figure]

GPIO / Python Testing

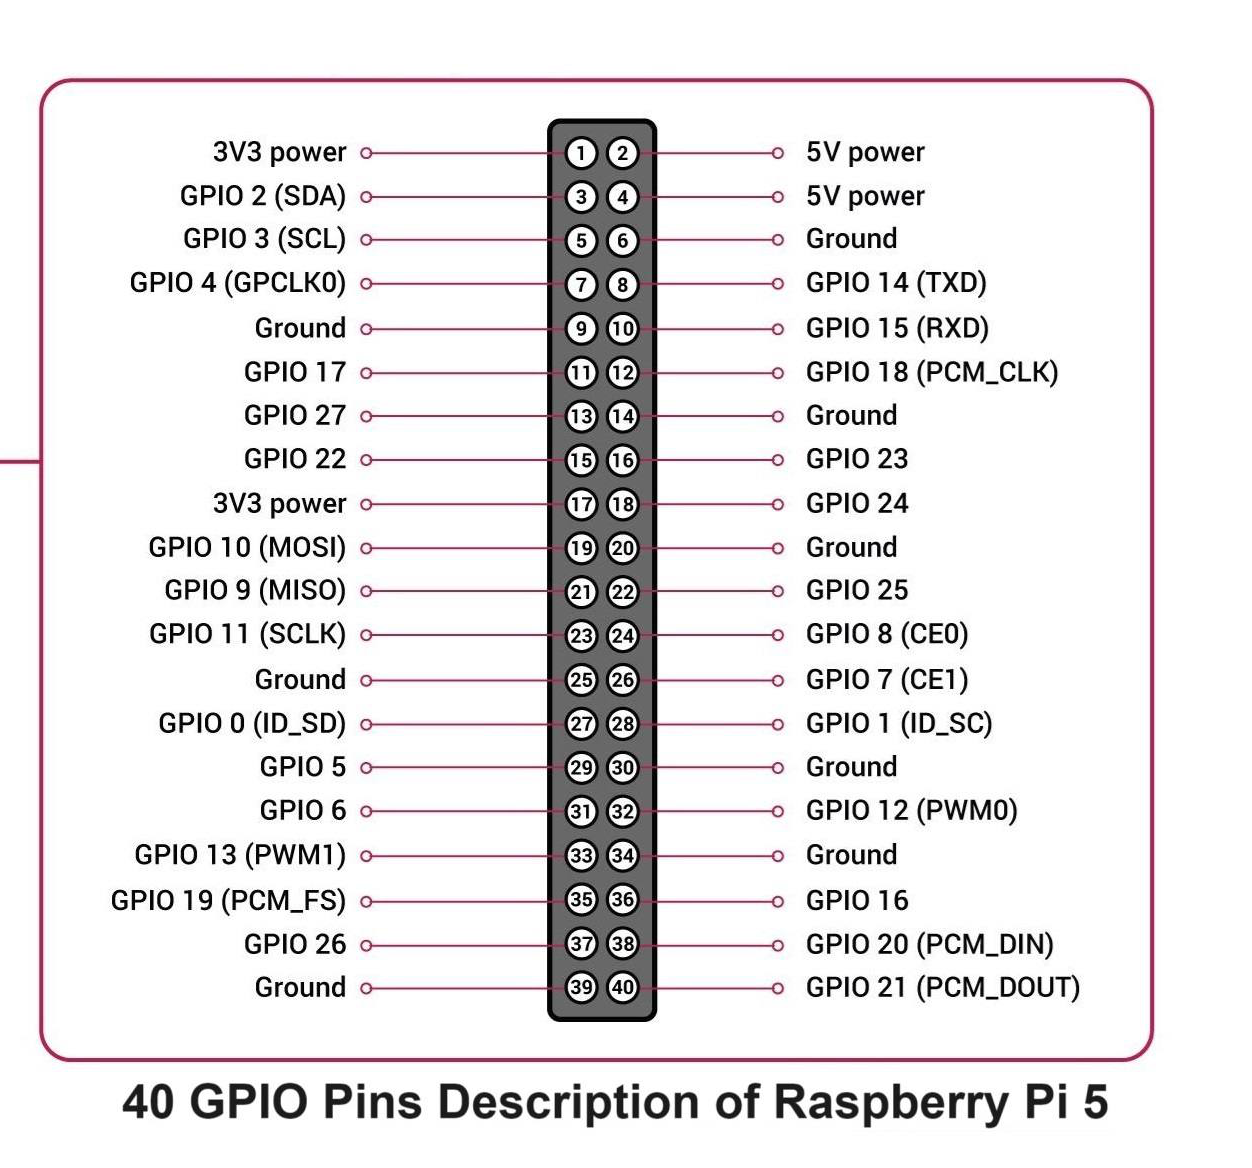
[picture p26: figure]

SSH Remote Access

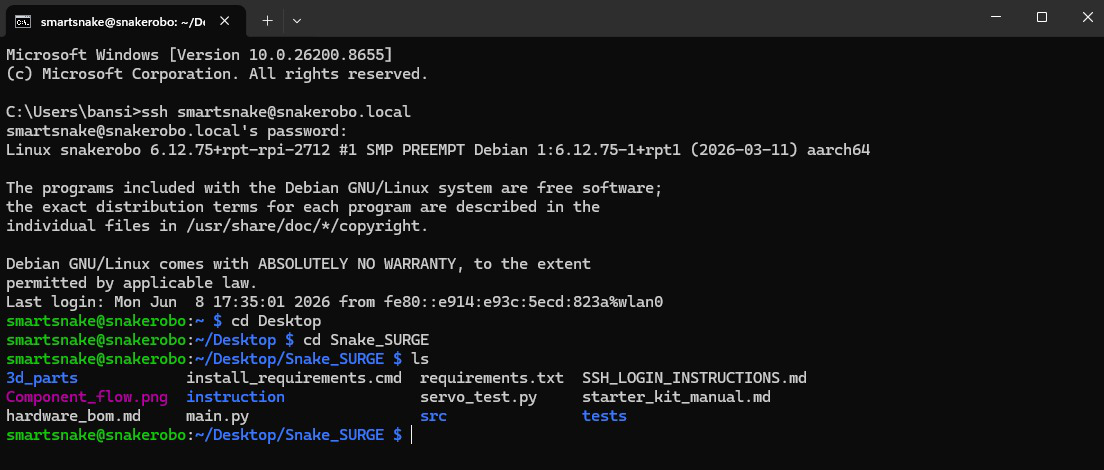
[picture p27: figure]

System Configuration

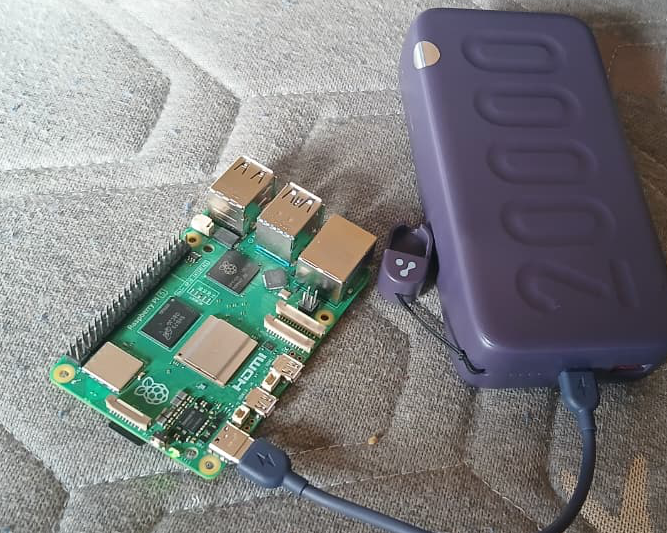
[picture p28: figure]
The image shows a purple rectangular device, presumably a Raspberry Pi E, with four black USB ports, placed on a wooden surface.

Raspberry Pi Platform Successfully Configured and Tested

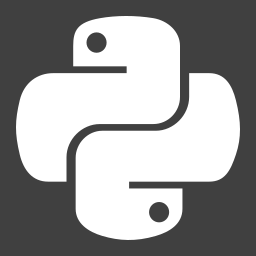
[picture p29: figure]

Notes: Control computer is live: OS installed, networked, remotely accessible, exercised with intro GPIO and Python. De-risks software before motors arrive.

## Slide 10

HARDWARE PROCUREMENT & RESOURCE AVAILABILITY

Hardware Procurement & Resource Availability

Hardware Strategy: Raspberry Pi 4 was planned in the BOM; however, a Raspberry Pi 5 was already available in the laboratory, enabling immediate software development and testing without waiting for delivery. To accelerate development, the team utilised the laboratory Raspberry Pi 5 platform while the ordered components remain under procurement.

DEVELOPMENT PROGRESS

Key Achievement: Although the primary Dynamixel hardware has not yet arrived, the team has successfully utilised available laboratory resources to complete design, fabrication, documentation, and software preparation activities, ensuring project progress is maintained.

AVAILABLE & IN USE

- Raspberry Pi 5 (Laboratory Resource)
- Raspberry Pi Starter Kit
- Raspberry Pi OS Environment
- GitHub Repository
- 3D Printed Prototype Segments

ORDERED — AWAITING DELIVERY

- Dynamixel XL330 Smart Servo Motors
- U2D2 Communication Interface
- U2D2 Power Hub Board
- Dynamixel Communication Cables
- 5V Power Supply
- ESP32 Development Board

COMPLETED PREPARATORY WORK

- Hardware selection finalised
- Bill of Materials prepared
- CAD model completed
- Segment fabrication initiated
- Software environment configured

✓

✓

✓

✓

✓

⏳

→

Component
Selection

Procurement
Initiated

CAD
Design

Prototype
Printing

RPi
Learning

Motor
Integration

Awaiting HW

Locomotion
Testing

Upcoming

★

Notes: Live BOM from the purchasing sheet. Compute hardware in hand; actuation and power chain ordered. Total approx Rs 33,760.

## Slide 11

REPOSITORY & DOCUMENTATION

Version Control From Day One

GitHub repository — project root & structure

Repository created
Central home for the whole project.

1

GITHUB REPOSITORY SCREENSHOTS

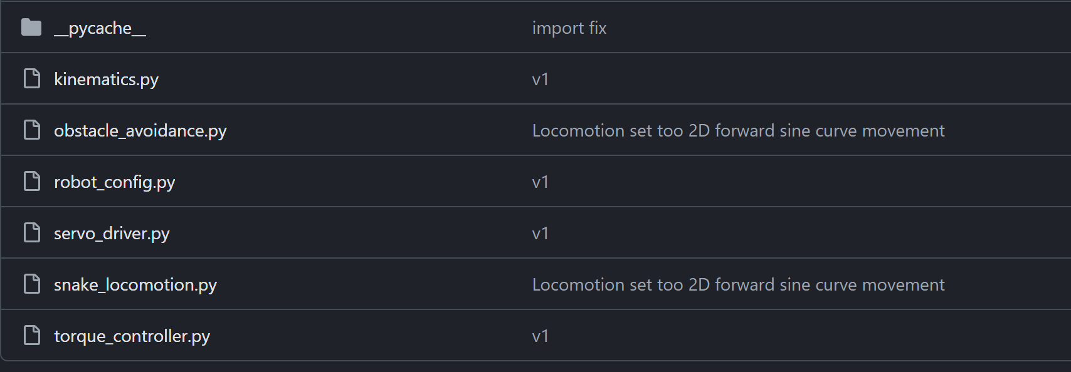
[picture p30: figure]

2

Version control established
Tracked, reversible change history.

CAD files uploaded
Design source committed to the repo.

3

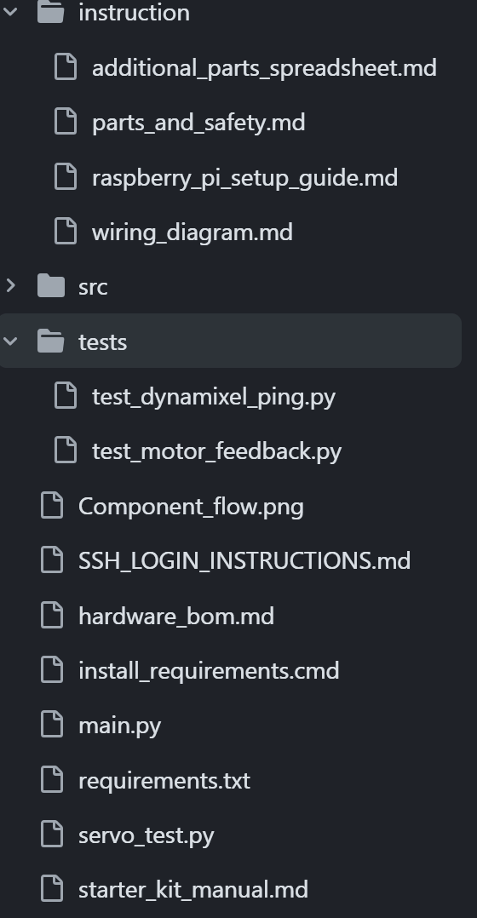
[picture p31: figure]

4

Design iterations documented
Every revision captured in commits.

Commit history — tracked iterations & uploads

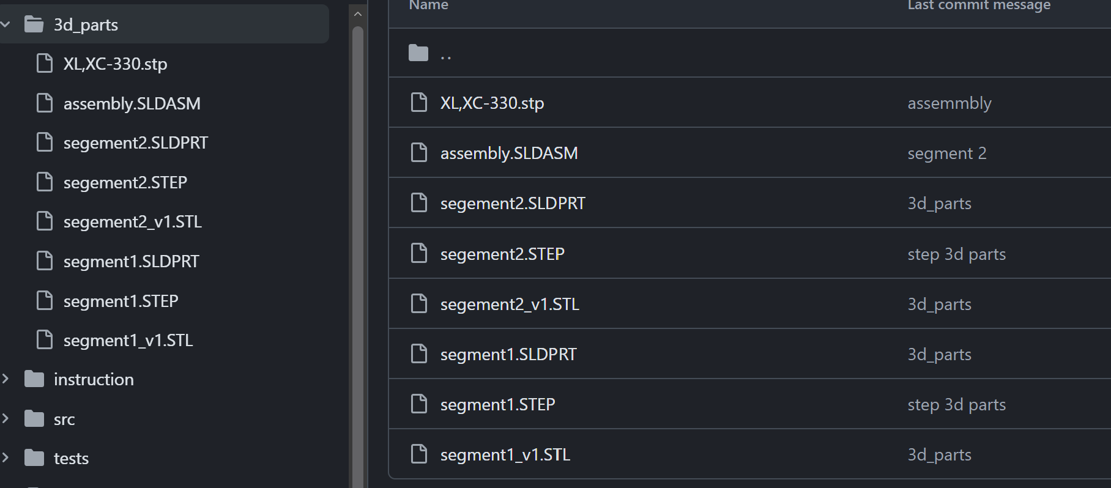
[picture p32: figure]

Progress tracking in place
Milestones and issues logged.

5

Team collaboration workflow
Shared branches and pull requests.

✓ All milestones tracked in GitHub

6

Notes: The repo is the single source of truth — CAD, docs, tracked iterations — with a collaboration workflow already running.

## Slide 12

PROJECT TIMELINE

Eight Phases · Currently at 25%

PHASE 1

Research & Design

Completed

PHASE 3

Mechanical Assembly

Up next

PHASE 5

Control Algorithms

PHASE 7

Testing & Optimisation

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
PHASE 2

Hardware Procurement

In progress

PHASE 4

Motor Integration

PHASE 6

Sensor Integration

PHASE 8

Final Demonstration

WE ARE HERE

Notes: Eight-phase plan: Phase 1 complete, Phase 2 active, Phase 3 next — about 25%. Phases 4-8 cover integration, control, sensing, testing, demo.

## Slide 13

CURRENT ACHIEVEMENTS

Concrete Wins in Quarter One

Architecture finalized

System block diagram locked.

CAD design completed

Segment modelled to motor specs.

Prototype fabrication started

Two segments printed & checked.

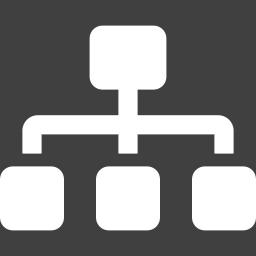
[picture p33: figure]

Pi environment established

OS, network and tooling ready.

GitHub workflow operational

Version control and docs live.

Procurement initiated

Core compute received; rest ordered.

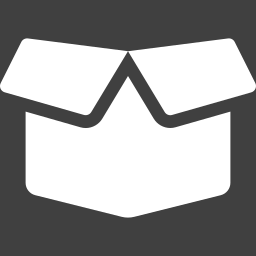
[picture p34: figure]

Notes: Six headline achievements: design, fabrication, compute, tooling and procurement all moving — a working foundation.

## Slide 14

SIMULATION & VALIDATION

Simulation-Based Validation of Control Architecture

Wokwi-based simulation environment developed to validate locomotion control, sensor integration, and communication architecture before physical Dynamixel hardware arrival.

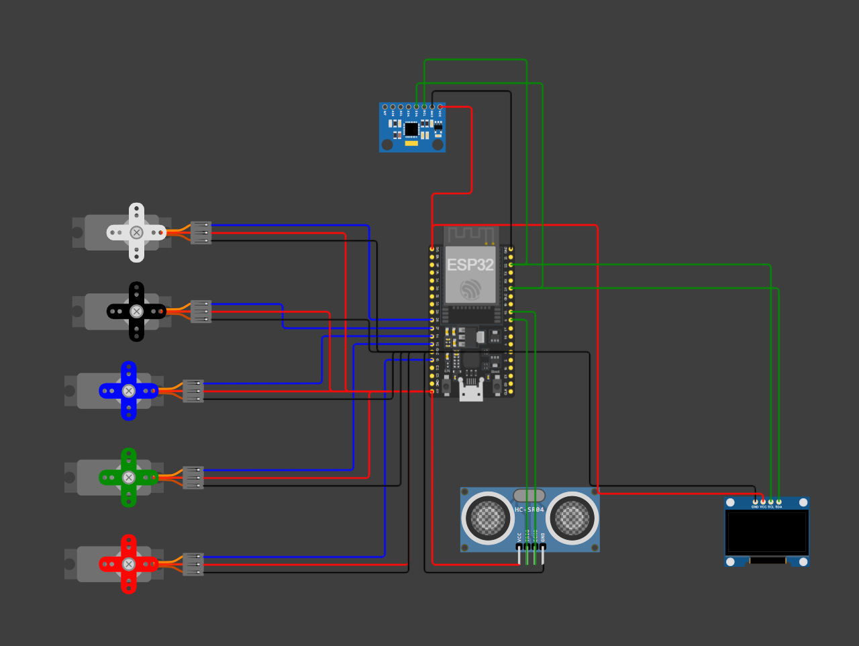
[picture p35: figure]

SIMULATION OBJECTIVE

A virtual testing platform to validate the control architecture before Dynamixel actuators and communication hardware arrive — enabling software development, algorithm verification, and sensor integration in parallel with procurement.

COMPONENTS SIMULATED

Controller

ESP32 · 5-Servo joint network · MPU6050 IMU · HC-SR04 ultrasonic · SSD1306 OLED · control & communication framework

FUNCTIONAL VALIDATION COMPLETED

- Multi-joint servo coordination
- Travelling-wave serpentine gait generation
- Obstacle detection via ultrasonic sensing
- IMU integration for orientation feedback
- OLED-based system status monitoring
- Sensor–controller–actuator communication

Sensors

Display

Actuators

ENGINEERING BENEFITS

- Reduced dependence on hardware delivery timelines
- Enabled early software debugging & control-architecture verification
- Established migration path to Raspberry Pi 5 + Dynamixel XL330, reducing integration risk

KEY OUTCOME A complete software-validation framework was developed, allowing locomotion, sensing, and control workflows to be tested before physical robot assembly.

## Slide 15

FUTURE WORK & DEVELOPMENT ROADMAP

Planned Activities for the Next Development Phase

Hardware Arrival

1

Mechanical Assembly

2

Communication Setup

3

Locomotion Development

4

Sensor Integration

5

Testing & Optimization

6

- Receive Dynamixel XL330 motors
- Receive U2D2 interface
- Verify purchased components

Completed phase

- Assemble complete snake body
- Install Dynamixel actuators
- Route communication cables

Ongoing work

- Configure motor IDs
- Establish serial communication
- Validate daisy-chain architecture

Future milestone

- Port simulation code to Pi 5
- Implement serpentine locomotion
- Synchronize multi-joint movement

- Integrate MPU6050 IMU
- Integrate obstacle detection
- Implement feedback control

- Motion performance testing
- Power & reliability analysis
- System optimization

EXPECTED DELIVERABLES

- Fully assembled snake robot
- Dynamixel-based locomotion
- Sensor-assisted navigation
- Integrated Raspberry Pi 5 control system
- Demonstration-ready prototype
- Final SURGE project showcase

TARGET FOR NEXT REVIEW

- Complete hardware integration
- Demonstrate basic snake locomotion
- Validate communication architecture
- Validate sensing framework

Goal: ~60–70% project completion

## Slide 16

WHAT CHANGED SINCE THIS REVIEW

Generation 2 — Corrections & Cause

Slides 1–15 are unchanged from the 25% review. This slide records what has since been superseded.

SLIDE | THAT DECK SAID | TODAY | WHY
10 | XL330 · U2D2 · Power Hub — “ORDERED, AWAITING DELIVERY” | Order cancelled. 10× ST3215 + Waveshare ESP32 driver in hand | Part unobtainable in India
12 | “Eight Phases · Currently at 25%” | Phase 3 — Fabrication & Assembly | Eight weeks of Gen 2 work since
13 | “Prototype fabrication started” | Gen 1 segments printed; Gen 2 v6 not yet printed | Design of record changed
15 | Roadmap step 1 — “Receive Dynamixel XL330 motors” | Superseded — see slide 29 | Different motors received

Constraint

WHAT HAPPENED

2 of 10 XL330 received, then the part vanished

Six-week stall

IMPACT

Control stack written against absent hardware

Re-architecture

COMMIT a32b675 · 2026-08-20

“No dynamixel in the market. So switched to Servos”

WHAT IT BOUGHT 5.7× joint torque (0.52 → 2.94 N·m) · a 12 V rail · sourceable in India — consequences of the switch, not its reason. Torque budget: slide 23.

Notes: Open by saying the deck up to this point is unchanged from the 25 percent review and is being left that way deliberately - those slides are a record of what we believed then, not a claim about now. Then walk the register top to bottom. It takes about forty seconds and it pre-empts every 'but slide 10 says' interruption in the second half. Say the honest version of the pivot out loud: this was a procurement failure, not an engineering preference, and a re-architecture under a supply constraint is a legitimate result. The follow-up question a reviewer asks is 'where is your torque budget' - it is slide 23, and it did not exist at the 25 percent review.

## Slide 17

ACTUATOR RE-SELECTION

From XL330 to Waveshare ST3215

XL330 VS ST3215 — AS SELECTED

Criterion | Dynamixel XL330 (Gen 1) | Waveshare ST3215 (Gen 2)
Stall torque | 0.52 N·m | 2.94 N·m — 5.7× higher
Voltage rail | 5 V | 6.0–12.6 V
Stall current | 0.35 A | 2.7 A @ 12 V
Encoder | 12-bit absolute | 12-bit absolute, 0–4095
Bus protocol | Dynamixel 2.0, 1 Mbps | Feetech STS, 1 Mbps half-duplex
Driver hardware | U2D2 + Power Hub + MCU | Waveshare driver, ESP32 onboard
Availability in India | Unobtainable | In stock — 10 units held

THE CONSTRAINT

The Gen 1 trade study was sound and its conclusion still holds: a snake robot needs smart serial bus servos. Only the vendor changed. XL330 became unobtainable in the Indian market after 2 of 10 units were received.

- Precise absolute position control
- Single-cable daisy-chain wiring
- Per-joint load and current feedback
- Built-in controller, no external driver per joint
- Scalable to 10 coordinated joints
- Procurable in India, in quantity

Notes: The Gen 1 trade study is not invalidated - its conclusion was smart bus servos, and that is what we still run. Only the vendor changed, and it changed for supply reasons, not engineering ones. The torque column is the favourable consequence: 5.7x more joint torque at the same joint count. The voltage change from 5 V to 12 V is what forced the power architecture rework on slide 24.

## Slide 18

GEN 1 → GEN 2 ARCHITECTURE

From Tethered Pi Control to Onboard ESP32

Control moved onto the robot · Pi 5 relegated to base station · Link is now wireless

OFF-ROBOT & PLANNED

MPU6050 IMU (I²C 21 / 22)

3S LiPo 1800 mAh (11.1 – 12.6 V)

Waveshare Driver + ESP32 [Robot Master]

Gait CPG runs onboard

ESP32 Camera (planned)

Feetech STS Bus (1 Mbps, half-duplex)

ESP-NOW → ESP32 #2 → Pi 5

10 × Waveshare ST3215 Servos

Robot Segments (10 × servo joints)

LEGEND

Implemented

In Progress

Generation 2 Implementation Status

Planned Future Work

All firmware targets written and building

Servo IDs not yet assigned — all ship as ID 1

v6 segments not yet printed

ESP-NOW link not yet exercised on hardware

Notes: The single most important change is where control lives. In Generation 1 the Raspberry Pi was the controller and sat on the robot, tethered over USB to a U2D2. In Generation 2 the ESP32 on the Waveshare driver is the master, the Pi 5 moved off the robot entirely, and the link between them is ESP-NOW rather than a cable. That is what makes untethered operation possible. Compare this against the Generation 1 block diagram on slide 6 - the shape of the system is genuinely different, not just re-labelled.

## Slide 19

ONBOARD FIRMWARE STACK

ESP32 Firmware — Four Targets, One Bus

Firmware Strategy: the Waveshare driver's onboard ESP32 is the robot master and owns the servo bus; a second ESP32 at the base station receives telemetry over ESP-NOW and forwards it to the Pi 5 by USB serial. Bench and field firmware are mutually exclusive on the driver board — one is flashed at a time.

FIRMWARE BRING-UP SEQUENCE

Key Achievement: all five firmware targets are written and compile clean under PlatformIO, and the broadcast smoke test drives all ten servos before any ID has been assigned — so the control stack was validated without waiting on bring-up.

ROBOT ESP32 — FIELD

- robot_esp32 — gait CPG, 10-DOF
- MPU6050 on I2C GPIO 21 / 22
- Current-stall obstacle FSM
- ESP-NOW telemetry transmit

BASE STATION ESP32 #2

- base_esp32 — ESP-NOW receive
- USB serial to Pi 5 @ 115200
- base_station.py logs telemetry

BENCH & BRING-UP TOOLS

- spin_all — broadcast smoke test
- assign_ids — one servo at a time
- usb_servo_bridge — Python stack
- PlatformIO, one env per sketch

✓

✓

✓

⏳

→

→

→

Firmware
written

PlatformIO
builds

Broadcast
smoke test

ID
assignment

Bus
verification

Gait on
hardware

Upcoming

ESP-NOW
telemetry

Upcoming

★

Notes: Three ESP32s in total, two on the robot and one at the base. The important design point is that video and telemetry are separate radio links: ESP-NOW carries telemetry, ordinary WiFi will carry camera video. Do not try to push video through ESP-NOW - the payload cap is 250 bytes. The bring-up rail is honest: we are at ID assignment, not past it.

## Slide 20

BUS PROTOCOL

Feetech STS Control Table & Packet Format

CONTROL TABLE — IMPLEMENTED

Register | Addr | Width and meaning
ID | 5 | 1 byte, EEPROM — factory default 1
TORQUE_ENABLE | 40 | 1 byte 0 = off, 1 = on
GOAL_POSITION | 42 | 2 bytes, little-endian, 0–4095
GOAL_SPEED | 46 | 2 bytes, steps per second
LOCK | 55 | 1 byte, EEPROM write gate
PRESENT_POSITION | 56 | 2 bytes, centre = 2048
PRESENT_CURRENT | 69 | 2 bytes, bit15 = sign, 6.5 mA/count

PACKET FORMAT

All ten servos share one half-duplex TTL line at 1 Mbps. Every packet is addressed to a single ID, or to broadcast ID 0xFE, which every servo acts on and none replies to — the only safe way to drive the bus before IDs are assigned.

- Header 0xFF 0xFF
- ID 1–253, or 0xFE broadcast
- Length parameters + 2
- Instruction 0x03 = WRITE, 0x02 = READ
- Parameters address, then data bytes
- Checksum bitwise NOT of the byte sum
- Multi-byte fields are little-endian

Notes: This is the whole interface. Two register facts matter downstream: GOAL_POSITION is little-endian and 0-4095 with centre 2048, which is a 4x scale difference from the SC-series servos the Waveshare board ships configured for; and PRESENT_CURRENT at address 69 is how we detect a stall, at 6.5 mA per count with the sign in bit 15. The 1200 mA threshold in robot_config.py is still a placeholder and needs calibrating against a real stall.

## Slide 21

CAD EVOLUTION

Segment Design v4 → v5 → v6

Design Strategy: the segment is a parametric CadQuery model, not a hand-drawn solid, so every dimension traces to a named constant and the model refuses to export if its own assumptions stop holding. v6 is the design of record; its three fixes were found by measuring the earlier versions rather than looking at them.

FABRICATION PIPELINE

Key Achievement: v6 caught three defects that v4 and v5 shared — the bottom plate sat 0.45 mm below the belly scales so 94% of ground contact was the one surface never meant to touch; the scales resisted the wrong axis for lateral undulation; and the motor had no positive retention at all.

V4 — BASELINE

- First parametric segment
- 58 mm joint-to-joint pitch
- Ground contact never measured
- Superseded, still printable

V5 — SUPERSEDED

- Widened yoke rectangle
- Early sidewall bug fixed
- Shares v4's bounding box
- Dimensional error — do not print

V6 — DESIGN OF RECORD

- Belly scales now touch ground
- Scales reoriented for undulation
- Positive M2 motor retention
- Self-check asserts all three

✓

✓

⏳

→

→

→

→

Parametric
model

Self-check
passes

Probe
ST3215 STEP

Print one
segment

Measure
friction

Print
remaining 10

Upcoming

Chain
assembly

Upcoming

★

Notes: The headline is that these defects were found by measurement, not by inspection - the model enumerates every face at minimum z and asserts which ones they are. Print v6, not v4 and definitely not v5. The friction measurement in step 5 is the real unknown: every locomotion claim in this deck assumes anisotropic belly friction that has never been measured on a printed part.

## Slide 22

STRUCTURE & LOAD PATH

v6 Load Path & Positive Motor Retention

v4 / v5 — Motor Lifts Straight Out

The motor sits in an open pocket with no fastener. Nothing resists it lifting out.

v6 — Captured in a Closed Cradle

Four M2 screws capture the motor against a closed cradle wall.

Horn

Slip-fit 0.4 mm

Open at top

Lightening windows

Horn

M2

M2

M2

M2

~1 mm rear wall

LOAD PATH

- Horn face transfers joint torque to the next segment
- F623ZZ flange bearing on the horn-opposite side
- Bearing carries radial load off the motor shaft
- 14 mm bolt circle, 4 × M2 blind holes each face
- Closed cradle wall reacts motor reaction torque

RETENTION — RESOLVED IN V6

Four M2 screws through a closed cradle

v4 and v5 relied on an interference fit alone. Under repeated gait loading that is a slow failure: the pocket wears, the motor rocks, and joint backlash grows. v6 adds positive fastening and restores the sidewall the lightening windows removed.

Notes: The load path point is that the motor shaft should not be carrying radial load - the F623ZZ bearing on the opposite face does that, and the horn only transfers torque. The retention fix matters more than it sounds: an interference fit that loosens turns into joint backlash, and backlash in a 10-joint chain compounds into a gait that will not track. This was found by measuring the pocket, not by looking at it.

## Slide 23

FRICTION, KEELS & TORQUE

Why v6 Can Actually Move — Friction & Torque Budget

v4 / v5 — Scales Never Touched Ground

The plate hung 0.45 mm below the scales — 94% of ground contact was the one surface never meant to touch.

v6 — Keels Carry the Robot

Scales swept along the body: grip across it, slide along it — the asymmetry lateral undulation requires.

Belly

Plate at −3.45 mm

Scales at −3.00 mm

Plate 1006 mm²

Belly

Grip

Slide

Grip

Slide

Scales 66 mm²

TORQUE BUDGET

- ST3215 stall torque 2.94 N·m at 12 V
- XL330 was 0.52 N·m — 5.7× less
- 10 joints, 58 mm pitch, ~580 mm body
- Head pod adds ≈ 0.02 N·m — under 1% of budget
- Torque is no longer the binding constraint

THE REMAINING UNKNOWN

Anisotropic friction ratio is unmeasured

Every locomotion claim in this deck assumes the belly grips across the body and slides along it. That ratio has never been measured on a printed part. Printing one v6 segment and measuring fore/aft versus lateral friction is the single highest-value next experiment.

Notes: Two halves. The torque half is settled - 5.7 times more joint torque than Generation 1, and the head pod barely registers against it, so torque stopped being the limiting factor the moment we switched actuators. The friction half is not settled and I want to be explicit about that. A snake robot moves by having different friction across the body than along it. v4 and v5 got that backwards and also never touched the ground with the feature that was supposed to do it. v6 fixes both in CAD, but nobody has put a printed segment on a surface and measured the ratio. Until that happens, the gait is theory.

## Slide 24

ELECTRICAL & POWER ARCHITECTURE

Field and Bench Power Paths

Robot rail resolved · No DC conversion needed · Protection hardware outstanding

BENCH PATH (TETHERED)

Mean Well LRS-100-5 (5 V, 20 A)

3S LiPo 1800 mAh — 20.0 Wh

Inline fuse + XT60 loop key [NOT YET HELD]

≈ 22 min at 4 A

12 V 2 A supply — ID assignment

1000 µF bulk capacitor [NOT YET HELD]

XL6009 boost — one servo only

Waveshare Driver VIN (6 – 12 V)

10 × ST3215 — 27 A worst-case stall

LEGEND

Implemented

In Progress

Power Status & Open Risks

Planned Future Work

LiPo sits inside the servo range — no conversion needed

Driver is rated 6–12 V; a full 3S pack is 12.6 V

Fuse, BMS and loop key are not yet in inventory

LiPo C-rating unverified — sets the real current ceiling

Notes: The resolved part is the robot rail: a 3S pack sits inside the ST3215's 6.0 to 12.6 volt window, so it feeds the driver directly with no buck or boost anywhere in the path. That removes the whole conversion problem Generation 1 had at 5 volts. Two things are not resolved and both belong on the record. First, Waveshare rates this board 6 to 12 volts, and a fully charged 3S pack is 12.6 - so we are 0.6 volts over spec at the top of every charge cycle. Second, none of the three protection parts are held yet. The 27 amp figure is worst-case all-joints-stalled, not normal draw, but it is what sizes the fuse.

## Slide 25

SAFETY ARCHITECTURE & CRITICAL GAPS

Five Protection Parts the Robot Does Not Yet Have

Inline fuse — MISSING

Nothing limits fault current on a 27 A-capable pack.

Loop-key disconnect — MISSING

No safe way to isolate the battery from the bus.

LiPo alarm / BMS — MISSING

No cell-level undervoltage protection below 3.0 V.

Bulk capacitor — MISSING

Servo inrush transients reach the driver unsuppressed.

Balance charger & bag — MISSING

No safe charge, balance or storage path for the pack.

Current-stall limit — IN FIRMWARE

Software torque cap works, but is not a fuse.

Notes: This is the slide I would rather not need. Five of the six cards are amber and they are all cheap - roughly 3600 rupees for the whole row. The reason it is on the deck rather than buried in a spreadsheet is that a 3S lithium polymer pack capable of 27 amps, with no fuse, no cell monitoring and no disconnect, is the one genuinely hazardous thing in this project. The sixth card is deliberate: the firmware current limit is real and it works, but software cannot protect against a short circuit. Nothing goes on the LiPo until the first three are fitted.

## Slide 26

GAIT & OBSTACLE RESPONSE

Gait Generation and the Evasion State Machine

Lateral Undulation — Travelling Wave

A serpenoid phase offset propagates down the chain at 50 Hz; amplitude 400 ticks ≈ 35°.

Evasion Finite State Machine

A sustained current rise trips STALL; the robot reverses, turns away, then resumes.

CPG

Joint 1 φ = 0°

Joint 2 φ = 72°

Joint 3 φ = 144°

FSM

RUN

STALL

BACK

TURN

Joint 4 φ = 216°

GAIT PARAMETERS

- Control loop 50 Hz
- Amplitude 400 encoder ticks ≈ 35°
- Phase offset 72° per joint, 10 joints
- Goal position written as a sync payload
- Gait continues if the IMU is absent

OBSTACLE DETECTION

Proprioceptive — no external sensor

Collision is inferred from PRESENT_CURRENT at address 69 rather than a rangefinder. The threshold is still a placeholder at 1200 mA and must be calibrated against a measured free-run and stall current before it can be trusted.

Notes: The gait is a central pattern generator - a travelling sine wave with a fixed phase offset per joint, which is the standard lateral undulation formulation. The part worth drawing attention to is obstacle detection: there is no ultrasonic sensor and no rangefinder in the loop. The robot notices an obstacle because a joint draws more current than it should, which is proprioception rather than exteroception. That is elegant and it costs nothing in hardware, but the threshold is a guess until we measure a real stall on a real segment.

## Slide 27

VERIFICATION & MOCK-MODE RESULTS

What Has Been Proven Without Hardware

v6 CAD self-check

Model refuses to export if its assumptions break.

Mock mode — SURGE_MOCK=1

Full gait stack runs with no servos attached.

Wokwi simulation

ESP32, servos, IMU and display validated virtually.

PlatformIO — five targets

All firmware environments compile clean.

Broadcast smoke test

Ten servos driven before any ID was assigned.

Hardware verification

Ping, stall calibration and gait still outstanding.

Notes: The honest framing is that this is verification without hardware, which is worth a lot but is not the same as a working robot. The five green cards are real: the CAD model asserts its own ground-contact geometry, the Python stack runs a full gait in mock mode, the simulation covers the electronics, every firmware target builds, and the broadcast test moved all ten servos on the bench. The amber card is the point of the slide - nothing has been calibrated against a real stall current yet, and that is the next measurement.

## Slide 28

INVENTORY, BUDGET & PROCUREMENT GAPS

What We Hold, What We Still Need

Budget Position: Gen 1 spend was approximately ₹33,760 of the ₹1,00,000 SURGE grant. Remaining procurement is estimated at ₹10,200 and is almost entirely consumables and safety hardware — the expensive actuator and compute line items are already held.

PROCUREMENT STATUS

Key Achievement: the actuator blocker that stalled Generation 1 is cleared — all ten servos, the driver board and the power source are in hand. Every remaining gap is a low-cost consumable, not a supply-chain risk.

IN HAND — 9 LINE ITEMS

- 10× Waveshare ST3215 servos
- Waveshare driver with ESP32
- ESP32 #2, Pi 5 8 GB, MPU6050
- 3S LiPo 1800 mAh, Mean Well 5 V
- Camera Module 3, XL6009 boost

MISSING — CRITICAL (SAFETY)

- Inline fuse and holder
- LiPo alarm / BMS module
- XT60 loop-key disconnect
- Without these the pack is unsafe

MISSING — HIGH PRIORITY

- 3S balance charger, storage bag
- Servo daisy-chain cables ×12
- F623ZZ bearings, M2 fasteners
- PLA+ filament, TPU belly pads

✓

✓

✓

⏳

→

→

→

Actuators
received

Compute
received

Power
source held

Safety
parts

Fasteners
& bearings

Filament
& pads

Upcoming

Camera
for ESP32

Upcoming

★

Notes: Be direct about the sunk Gen 1 cost. The favourable point is that Gen 2 needs only consumables and safety parts and the grant covers it comfortably. The critical row is not optional - running a 3S LiPo with no fuse, no BMS and no disconnect is the one genuinely unsafe thing in this project. Verify the ST3215 purchase cost before presenting; the inventory lists them as held but records no price.

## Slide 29

ROADMAP

Path to Demonstration — Generation 2

Replaces the Generation 1 roadmap on slide 15, which was written around Dynamixel XL330 delivery and is now obsolete.

PHASE 1

Power Verification

In progress

PHASE 3

Segment Fabrication

Planned

PHASE 5

Field Integration

PHASE 7

Characterisation

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
PHASE 2

Servo Bring-Up

Up next

PHASE 4

Mechanical Assembly

PHASE 6

Locomotion Trials

PHASE 8

Final Demonstration

WE ARE HERE

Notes: Open by naming slide 15 and saying plainly that it is superseded - do not let the audience find two roadmaps on their own and wonder which one is live. The eight phases here are the actual next steps from the hardware inventory, not a re-skin of the old plan. Phase 1 is where we are: the pack cannot go on the robot until the fuse, loop key and BMS are fitted. Close on phase 3, because it contains the one experiment everything else depends on - printing a v6 segment and measuring whether the belly friction is actually anisotropic. If it is not, the gait does not work and we would rather know that before printing ten more segments. Target for the next review is first translating locomotion on hardware, which is a milestone you can watch rather than a percentage you have to trust.

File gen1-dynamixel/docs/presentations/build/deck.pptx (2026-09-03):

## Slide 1

GROUP CODE · SURGE 090

INSTITUTION

Indian Institute of Technology, Delhi

Progress Review (Design & Development)

Smart Snake Robot

with Dynamixel Smart Servo Motors

PROJECT GUIDE

Professor Amartansh Dubey

Shashank Jangir

ENTRY NO.

2024EE11048

Bhavesh Bansiwal

ENTRY NO.

2024ME10487

Mahima Chotiya

ENTRY NO.

2024ME11187

PROJECT REPOSITORY

https://github.com/shashankjangir/SurGe-090-Smart-snake-robot

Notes: Title slide for the 25% progress review of the Smart Snake Robot project, Group SURGE 090. Introduce the team and milestone scope.

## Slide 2

ACTUATOR SELECTION STUDY

Why Dynamixel Motors?

OPTIONS COMPARED

Criterion | Conventional Servo | Dynamixel Smart Servo
Communication | Individual signal wire per motor | Daisy-chain communication
Wiring Complexity | High | Low
Feedback | Not available | Position, load, temperature, voltage feedback
Controller | External controller required | Built-in controller
Scalability | Difficult for many joints | Designed for multi-joint robots
Precision | Moderate | High
Robotics Applications | Hobby projects | Research and industrial robotics

THE REQUIREMENT

A snake robot drives many joints at once. The actuator must deliver:

- Precise position control
- Simple wiring architecture
- Scalability for multiple joints
- Reliable communication
- Real-time feedback
- Compact size & sufficient torque


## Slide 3

ARCHITECTURE & DECISION

Daisy-Chain Architecture & Final Selection

Conventional Servo — Separate Wiring

Every motor needs its own signal wire back to the controller.

Dynamixel — Daisy-Chain

One cable carries power and data to every joint in sequence.

Controller

Servo 1

Servo 2

Servo 3

Ctrl

M1

M2

M3

M4

Servo 4

KEY LEARNINGS

- Daisy-chain wiring sharply cuts cabling and assembly effort.
- A controller built into every motor simplifies integration.
- Real-time feedback enables future closed-loop control.
- Compact form factor suits modular robot segments.
- High precision and smart control fit advanced robotics.

FINAL SELECTED ACTUATOR

Dynamixel XL330 Series

Chosen for its smart serial communication, full-state feedback, compact form factor and effortless multi-joint scaling — the right fit for a multi-segment snake robot.

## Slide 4

GOALS & EXPECTED OUTCOMES

What This Project Sets Out to Build

Modular Architecture

A repeatable segment-based mechanical design.

Dynamixel Actuators

Integrate smart servos with daisy-chained control.

Raspberry Pi Control

A single-board-computer control system.

01

02

03

Locomotion Algorithms

Implement serpentine and gait-based motion.

Sensor Integration

Add sensing for future intelligent navigation.

Scalable Platform

Keep it maintainable and easy to extend.

04

05

06

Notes: Six concrete goals across mechanics, actuation, computing, control, sensing and scalability. These map to the timeline phases.

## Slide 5

WORK COMPLETED SO FAR

Quarter-One Progress Summary

COMPLETED TASKS

OVERALL COMPLETION(till now)

25 %

Phase 1 complete · Phase 2 underway

Literature review & project understanding

Raspberry Pi setup & configuration

Hardware selection & BOM preparation

Wi-Fi connectivity testing on the Pi

CAD design of snake-robot segment

Basic Raspberry Pi lab projects executed

10

Tasks done

2

Segments printed

1

Pi configured

Assembly sized to Dynamixel XL330 dims

GitHub repository created & maintained

3D printing of two prototype segments

Procurement process initiated

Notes: About a quarter done: ten tasks closed across research, mechanical design, fabrication and the compute platform.

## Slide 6

SYSTEM ARCHITECTURE

Conceptual Block Diagram

Architecture finalized · Implementation in progress

FUTURE INTEGRATION

IMU / Force Sensors

Power Supply

Raspberry Pi 5 [Central Controller]

Control Algorithms

Camera Module

Communication Layer (U2D2 / UART)

Wireless Control Module

Dynamixel Motor Network

Robot Segments (10 × servo joints)

LEGEND

Implemented

In Progress

Current Implementation Status

Planned Future Work

Raspberry Pi 5 configured and tested

Communication architecture defined

Mechanical segments fabricated

Dynamixel integration pending hardware

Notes: Controller at the centre. Solid cyan = implemented/in progress; dashed amber (sensors, camera) = designed-in but scheduled for a later phase.

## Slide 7


ASSEMBLY FLOW

Motor → Segment Parts → Full Chain Assembly

③ Full Assembly

CAD DESIGN DEVELOPMENT

A Segment Designed Around the Motor

The CAD model is built to the exact dimensions of the Dynamixel XL330-M288 servo, using a modular, segment-based architecture focused on manufacturability and scalability.

DESIGN CONSIDERATIONS

Motor mounting — Precise seats for XL330 servo bodies.


Structural rigidity — Stiff frame to resist motion loads.


Cable routing — Clean daisy-chain channels for wiring.


Electronics ready — Space reserved for future boards.

① Motor

② Segment Parts

③ Full Assembly

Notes: CAD modelled to real XL330 dimensions so printed parts mate with the actual servos. Replace the placeholder with CAD screenshots.

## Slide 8

PROTOTYPE FABRICATION

From Model to Printed Hardware

PRINTED SEGMENT — PHOTO 1

Insert photo of the first 3D-printed segment

The image shows a white, rectangular piece of furniture, possibly a desk or shelf, resting on a patterned carpet with a few scattered fabric scraps nearby.

FABRICATION STATUS

Two prototype segments 3D printed

Both segments produced from the CAD model.

DONE

Initial dimensional verification done

Printed parts measured against design specs.

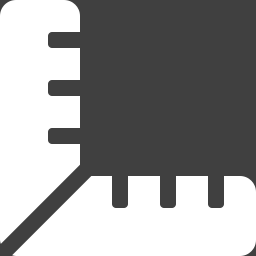
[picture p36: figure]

DONE

PRINTED SEGMENT — PHOTO 2

Insert photo of the second segment / assembly


Physical validation of CAD initiated

Checking fit, tolerances and assembly.

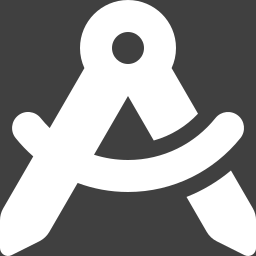
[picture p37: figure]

NEXT

Preparing for motor-integration tests

Next: seat XL330 servos into segments.

NEXT

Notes: Two segments printed and measured, validating the CAD. Next step is servo integration. Drop prototype photos on the left.

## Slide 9

RASPBERRY PI LEARNING & DEVELOPMENT

Standing Up the Compute Platform

PROGRESS MILESTONES

Raspberry Pi 5 received & configured

Raspberry Pi OS installation completed

Wi-Fi connectivity established

SSH & remote access explored

Basic GPIO & intro projects performed

Linux environment & Python familiarity

Development Environment Setup

Raspberry Pi OS Desktop


GPIO / Python Testing

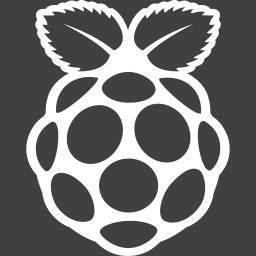
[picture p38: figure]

SSH Remote Access


System Configuration

The image shows a purple rectangular device, presumably a Raspberry Pi E, with four black USB ports, placed on a wooden surface.

Raspberry Pi Platform Successfully Configured and Tested


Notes: Control computer is live: OS installed, networked, remotely accessible, exercised with intro GPIO and Python. De-risks software before motors arrive.

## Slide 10

HARDWARE PROCUREMENT & RESOURCE AVAILABILITY

Hardware Procurement & Resource Availability

Hardware Strategy: Raspberry Pi 4 was planned in the BOM; however, a Raspberry Pi 5 was already available in the laboratory, enabling immediate software development and testing without waiting for delivery. To accelerate development, the team utilised the laboratory Raspberry Pi 5 platform while the ordered components remain under procurement.

DEVELOPMENT PROGRESS

Key Achievement: Although the primary Dynamixel hardware has not yet arrived, the team has successfully utilised available laboratory resources to complete design, fabrication, documentation, and software preparation activities, ensuring project progress is maintained.

AVAILABLE & IN USE

- Raspberry Pi 5 (Laboratory Resource)
- Raspberry Pi Starter Kit
- Raspberry Pi OS Environment
- GitHub Repository
- 3D Printed Prototype Segments

ORDERED — AWAITING DELIVERY

- Dynamixel XL330 Smart Servo Motors
- U2D2 Communication Interface
- U2D2 Power Hub Board
- Dynamixel Communication Cables
- 5V Power Supply
- ESP32 Development Board

COMPLETED PREPARATORY WORK

- Hardware selection finalised
- Bill of Materials prepared
- CAD model completed
- Segment fabrication initiated
- Software environment configured

✓

✓

✓

✓

✓

⏳

→

Component
Selection

Procurement
Initiated

CAD
Design

Prototype
Printing

RPi
Learning

Motor
Integration

Awaiting HW

Locomotion
Testing

Upcoming

★

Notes: Live BOM from the purchasing sheet. Compute hardware in hand; actuation and power chain ordered. Total approx Rs 33,760.

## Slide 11

REPOSITORY & DOCUMENTATION

Version Control From Day One

GitHub repository — project root & structure

Repository created
Central home for the whole project.

1

GITHUB REPOSITORY SCREENSHOTS


2

Version control established
Tracked, reversible change history.

CAD files uploaded
Design source committed to the repo.

3


4

Design iterations documented
Every revision captured in commits.

Commit history — tracked iterations & uploads


Progress tracking in place
Milestones and issues logged.

5

Team collaboration workflow
Shared branches and pull requests.

✓ All milestones tracked in GitHub

6

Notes: The repo is the single source of truth — CAD, docs, tracked iterations — with a collaboration workflow already running.

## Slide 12

PROJECT TIMELINE

Eight Phases · Currently at 25%

PHASE 1

Research & Design

Completed

PHASE 3

Mechanical Assembly

Up next

PHASE 5

Control Algorithms

PHASE 7

Testing & Optimisation

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
PHASE 2

Hardware Procurement

In progress

PHASE 4

Motor Integration

PHASE 6

Sensor Integration

PHASE 8

Final Demonstration

WE ARE HERE

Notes: Eight-phase plan: Phase 1 complete, Phase 2 active, Phase 3 next — about 25%. Phases 4-8 cover integration, control, sensing, testing, demo.

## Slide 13

CURRENT ACHIEVEMENTS

Concrete Wins in Quarter One

Architecture finalized

System block diagram locked.

CAD design completed

Segment modelled to motor specs.

Prototype fabrication started

Two segments printed & checked.

Pi environment established

OS, network and tooling ready.

GitHub workflow operational

Version control and docs live.

Procurement initiated

Core compute received; rest ordered.


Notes: Six headline achievements: design, fabrication, compute, tooling and procurement all moving — a working foundation.

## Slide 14

SIMULATION & VALIDATION

Simulation-Based Validation of Control Architecture

Wokwi-based simulation environment developed to validate locomotion control, sensor integration, and communication architecture before physical Dynamixel hardware arrival.


SIMULATION OBJECTIVE

A virtual testing platform to validate the control architecture before Dynamixel actuators and communication hardware arrive — enabling software development, algorithm verification, and sensor integration in parallel with procurement.

COMPONENTS SIMULATED

Controller

ESP32 · 5-Servo joint network · MPU6050 IMU · HC-SR04 ultrasonic · SSD1306 OLED · control & communication framework

FUNCTIONAL VALIDATION COMPLETED

- Multi-joint servo coordination
- Travelling-wave serpentine gait generation
- Obstacle detection via ultrasonic sensing
- IMU integration for orientation feedback
- OLED-based system status monitoring
- Sensor–controller–actuator communication

Sensors

Display

Actuators

ENGINEERING BENEFITS

- Reduced dependence on hardware delivery timelines
- Enabled early software debugging & control-architecture verification
- Established migration path to Raspberry Pi 5 + Dynamixel XL330, reducing integration risk

KEY OUTCOME A complete software-validation framework was developed, allowing locomotion, sensing, and control workflows to be tested before physical robot assembly.

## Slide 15

FUTURE WORK & DEVELOPMENT ROADMAP

Planned Activities for the Next Development Phase

Hardware Arrival

1

Mechanical Assembly

2

Communication Setup

3

Locomotion Development

4

Sensor Integration

5

Testing & Optimization

6

- Receive Dynamixel XL330 motors
- Receive U2D2 interface
- Verify purchased components

Completed phase

- Assemble complete snake body
- Install Dynamixel actuators
- Route communication cables

Ongoing work

- Configure motor IDs
- Establish serial communication
- Validate daisy-chain architecture

Future milestone

- Port simulation code to Pi 5
- Implement serpentine locomotion
- Synchronize multi-joint movement

- Integrate MPU6050 IMU
- Integrate obstacle detection
- Implement feedback control

- Motion performance testing
- Power & reliability analysis
- System optimization

EXPECTED DELIVERABLES

- Fully assembled snake robot
- Dynamixel-based locomotion
- Sensor-assisted navigation
- Integrated Raspberry Pi 5 control system
- Demonstration-ready prototype
- Final SURGE project showcase

TARGET FOR NEXT REVIEW

- Complete hardware integration
- Demonstrate basic snake locomotion
- Validate communication architecture
- Validate sensing framework

Goal: ~60–70% project completion

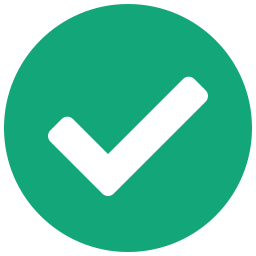
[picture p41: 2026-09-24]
gen1-dynamixel/docs/presentations/build/pristine/ppt/media/image11.png

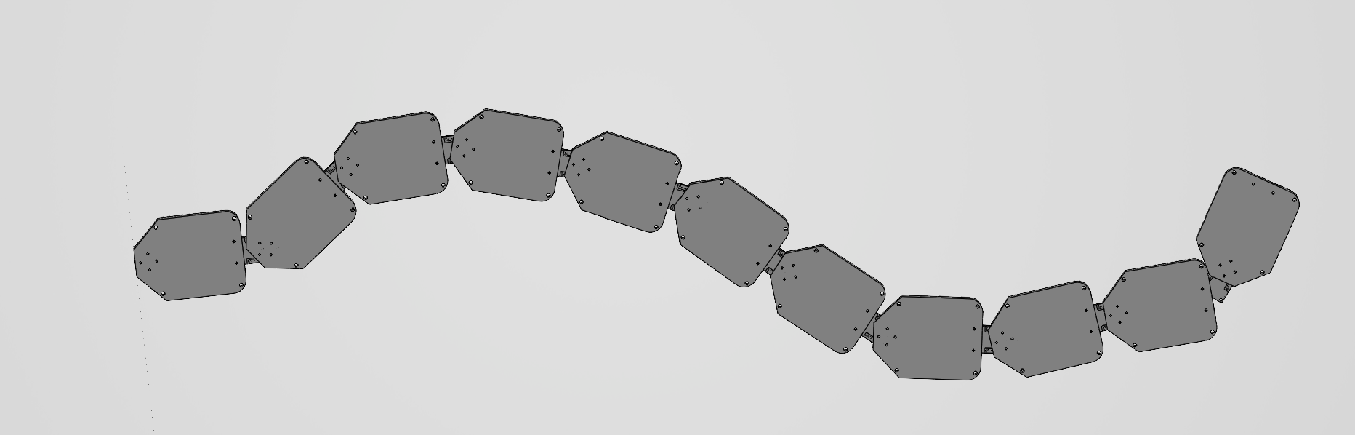
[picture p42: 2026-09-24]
gen1-dynamixel/docs/presentations/build/pristine/ppt/media/image17.png

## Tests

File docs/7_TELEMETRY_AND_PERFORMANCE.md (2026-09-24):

# Telemetry, Diagnostics & Performance

This document outlines the onboard diagnostic tools (RGB LEDs) and the theoretical performance latency of the Snake SURGE architecture.

## 1. RGB LED Status Indicators
The Receiver ESP32 (Waveshare Servo Driver) features two WS2812 RGB NeoPixel LEDs on GPIO 23 that provide real-time hardware status and telemetry feedback.

### LED 0: Connection Status (Left LED)
Indicates the current communication link between the master controller and the ESP32.
* **🤍 Slow Breathing White:** Disconnected / Waiting for a signal.
* **🟦 Solid Blue:** USB Serial connection active.
* **🟩 Solid Green:** Wireless (ESP-NOW) connection active.
* **🟦🟩 Solid Cyan:** Both USB and Wireless are active simultaneously.

### LED 1: Motor Telemetry & Error Status (Right LED)
Monitors the physical effort (current/load) of all 10 ST3215 motors in real-time. This LED updates dynamically when the web app requests telemetry.
* **🟩 Solid Green (Normal):** The snake is slithering with minimal resistance (Max Load < 30%).
* **🟨 Solid Yellow (Moderate):** The snake is working hard or pushing against friction (Max Load 30% - 60%).
* **🟥 Flashing Red (Warning/Danger):** Overload! One or more motors are stalling or pushing past 60% load. Be aware that prolonged stalling may trigger the power supply's over-current protection.
* **🛑 Solid Red (Hardware Error):** The ESP32 is attempting to poll the servos, but zero servos are responding. Check the daisy-chain wiring and motor power.

---

## 2. System Pipeline Latency
The Snake SURGE architecture is designed for extreme low-latency performance. Because it bypasses traditional Wi-Fi routers (using ESP-NOW) and uses 1 Mbps TTL communication to the motors, the input delay is virtually unnoticeable.

Below is the calculated one-way latency from the Python Web App generating a path, to the physical motor starting its movement:

### Step 1: Raspberry Pi ➡️ Transmitter ESP32 (USB Serial)
* **Baud Rate:** 115,200 bps
* **Data Payload:** ~80 bytes for 10 motor coordinates (640 bits)
* **Calculation:** (640 / 115,200) + ~1ms Linux USB overhead
* **Delay:** **~6.5 ms**

### Step 2: Transmitter ➡️ Receiver (ESP-NOW Wireless)
* **Protocol:** 2.4 GHz direct Wi-Fi hardware layer (router-less)
* **Calculation:** ESP-NOW bypasses the standard TCP/IP stack for ultra-low latency.
* **Delay:** **~1.5 ms**

### Step 3: Receiver ESP32 Processing
* **Hardware:** 240 MHz Dual-Core Processor
* **Tasks:** Parsing the CSV string, updating the OLED, updating WS2812 LEDs.
* **Calculation:** WS2812 protocol requires ~0.11 ms for 2 pixels. String parsing takes microseconds.
* **Delay:** **~0.2 ms**

### Step 4: Receiver ➡️ Servos (Physical Serial1)
* **Baud Rate:** 1,000,000 bps (1 Mbps)
* **Data Payload:** 10 individual `WritePosEx` packets (~15 bytes each = 1500 bits)
* **Calculation:** (1500 / 1,000,000) + ~0.5ms inter-packet spacing
* **Delay:** **~2.0 ms**

### Total Pipeline Latency: ~10.2 Milliseconds
A one-way delay of **10.2 ms** means the snake is physically executing movements faster than a standard 60Hz video game monitor can draw a single frame (16.6 ms). This guarantees perfectly smooth, fluid biological motion without stuttering or input lag.

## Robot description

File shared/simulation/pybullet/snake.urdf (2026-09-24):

<?xml version="1.0"?>
<robot name="snake">
  <material name="blue">
    <color rgba="0 0 1 1"/>
  </material>

  <link name="link0">
    <visual>
      <geometry>
        <box size="0.06 0.055 0.055"/>
      </geometry>
      <origin xyz="0.03 0 0"/>
      <material name="blue"/>
    </visual>
    <collision>
      <geometry>
        <box size="0.06 0.055 0.055"/>
      </geometry>
      <origin xyz="0.03 0 0"/>
    </collision>
    <inertial>
      <mass value="0.1"/>
      <origin xyz="0.03 0 0"/>
      <inertia ixx="0.0001" ixy="0" ixz="0" iyy="0.0001" iyz="0" izz="0.0001"/>
    </inertial>
  </link>

  <joint name="joint0" type="revolute">
    <parent link="link0"/>
    <child link="link1"/>
    <origin xyz="0.06 0 0"/>
    <axis xyz="0 0 1"/>
    <limit lower="-1.5" upper="1.5" effort="10" velocity="5"/>
  </joint>

  <link name="link1">
    <visual>
      <geometry>
        <box size="0.06 0.055 0.055"/>
      </geometry>
      <origin xyz="0.03 0 0"/>
      <material name="blue"/>
    </visual>
    <collision>
      <geometry>
        <box size="0.06 0.055 0.055"/>
      </geometry>
      <origin xyz="0.03 0 0"/>
    </collision>
    <inertial>
      <mass value="0.1"/>
      <origin xyz="0.03 0 0"/>
      <inertia ixx="0.0001" ixy="0" ixz="0" iyy="0.0001" iyz="0" izz="0.0001"/>
    </inertial>
  </link>

  <joint name="joint1" type="revolute">
    <parent link="link1"/>
    <child link="link2"/>
    <origin xyz="0.06 0 0"/>
    <axis xyz="0 0 1"/>
    <limit lower="-1.5" upper="1.5" effort="10" velocity="5"/>
  </joint>

  <link name="link2">
    <visual>
      <geometry>
        <box size="0.06 0.055 0.055"/>
      </geometry>
      <origin xyz="0.03 0 0"/>
      <material name="blue"/>
    </visual>
    <collision>
      <geometry>
        <box size="0.06 0.055 0.055"/>
      </geometry>
      <origin xyz="0.03 0 0"/>
    </collision>
    <inertial>
      <mass value="0.1"/>
      <origin xyz="0.03 0 0"/>
      <inertia ixx="0.0001" ixy="0" ixz="0" iyy="0.0001" iyz="0" izz="0.0001"/>
    </inertial>
  </link>

  <joint name="joint2" type="revolute">
    <parent link="link2"/>
    <child link="link3"/>
    <origin xyz="0.06 0 0"/>
    <axis xyz="0 0 1"/>
    <limit lower="-1.5" upper="1.5" effort="10" velocity="5"/>
  </joint>

  <link name="link3">
    <visual>
      <geometry>
        <box size="0.06 0.055 0.055"/>
      </geometry>
      <origin xyz="0.03 0 0"/>
      <material name="blue"/>
    </visual>
    <collision>
      <geometry>
        <box size="0.06 0.055 0.055"/>
      </geometry>
      <origin xyz="0.03 0 0"/>
    </collision>
    <inertial>
      <mass value="0.1"/>
      <origin xyz="0.03 0 0"/>
      <inertia ixx="0.0001" ixy="0" ixz="0" iyy="0.0001" iyz="0" izz="0.0001"/>
    </inertial>
  </link>

  <joint name="joint3" type="revolute">
    <parent link="link3"/>
    <child link="link4"/>
    <origin xyz="0.06 0 0"/>
    <axis xyz="0 0 1"/>
    <limit lower="-1.5" upper="1.5" effort="10" velocity="5"/>
  </joint>

  <link name="link4">
    <visual>
      <geometry>
        <box size="0.06 0.055 0.055"/>
      </geometry>
      <origin xyz="0.03 0 0"/>
      <material name="blue"/>
    </visual>
    <collision>
      <geometry>
        <box size="0.06 0.055 0.055"/>
      </geometry>
      <origin xyz="0.03 0 0"/>
    </collision>
    <inertial>
      <mass value="0.1"/>
      <origin xyz="0.03 0 0"/>
      <inertia ixx="0.0001" ixy="0" ixz="0" iyy="0.0001" iyz="0" izz="0.0001"/>
    </inertial>
  </link>

  <joint name="joint4" type="revolute">
    <parent link="link4"/>
    <child link="link5"/>
    <origin xyz="0.06 0 0"/>
    <axis xyz="0 0 1"/>
    <limit lower="-1.5" upper="1.5" effort="10" velocity="5"/>
  </joint>

  <link name="link5">
    <visual>
      <geometry>
        <box size="0.06 0.055 0.055"/>
      </geometry>
      <origin xyz="0.03 0 0"/>
      <material name="blue"/>
    </visual>
    <collision>
      <geometry>
        <box size="0.06 0.055 0.055"/>
      </geometry>
      <origin xyz="0.03 0 0"/>
    </collision>
    <inertial>
      <mass value="0.1"/>
      <origin xyz="0.03 0 0"/>
      <inertia ixx="0.0001" ixy="0" ixz="0" iyy="0.0001" iyz="0" izz="0.0001"/>
    </inertial>
  </link>

  <joint name="joint5" type="revolute">
    <parent link="link5"/>
    <child link="link6"/>
    <origin xyz="0.06 0 0"/>
    <axis xyz="0 0 1"/>
    <limit lower="-1.5" upper="1.5" effort="10" velocity="5"/>
  </joint>

  <link name="link6">
    <visual>
      <geometry>
        <box size="0.06 0.055 0.055"/>
      </geometry>
      <origin xyz="0.03 0 0"/>
      <material name="blue"/>
    </visual>
    <collision>
      <geometry>
        <box size="0.06 0.055 0.055"/>
      </geometry>
      <origin xyz="0.03 0 0"/>
    </collision>
    <inertial>
      <mass value="0.1"/>
      <origin xyz="0.03 0 0"/>
      <inertia ixx="0.0001" ixy="0" ixz="0" iyy="0.0001" iyz="0" izz="0.0001"/>
    </inertial>
  </link>

  <joint name="joint6" type="revolute">
    <parent link="link6"/>
    <child link="link7"/>
    <origin xyz="0.06 0 0"/>
    <axis xyz="0 0 1"/>
    <limit lower="-1.5" upper="1.5" effort="10" velocity="5"/>
  </joint>

  <link name="link7">
    <visual>
      <geometry>
        <box size="0.06 0.055 0.055"/>
      </geometry>
      <origin xyz="0.03 0 0"/>
      <material name="blue"/>
    </visual>
    <collision>
      <geometry>
        <box size="0.06 0.055 0.055"/>
      </geometry>
      <origin xyz="0.03 0 0"/>
    </collision>
    <inertial>
      <mass value="0.1"/>
      <origin xyz="0.03 0 0"/>
      <inertia ixx="0.0001" ixy="0" ixz="0" iyy="0.0001" iyz="0" izz="0.0001"/>
    </inertial>
  </link>

  <joint name="joint7" type="revolute">
    <parent link="link7"/>
    <child link="link8"/>
    <origin xyz="0.06 0 0"/>
    <axis xyz="0 0 1"/>
    <limit lower="-1.5" upper="1.5" effort="10" velocity="5"/>
  </joint>

  <link name="link8">
    <visual>
      <geometry>
        <box size="0.06 0.055 0.055"/>
      </geometry>
      <origin xyz="0.03 0 0"/>
      <material name="blue"/>
    </visual>
    <collision>
      <geometry>
        <box size="0.06 0.055 0.055"/>
      </geometry>
      <origin xyz="0.03 0 0"/>
    </collision>
    <inertial>
      <mass value="0.1"/>
      <origin xyz="0.03 0 0"/>
      <inertia ixx="0.0001" ixy="0" ixz="0" iyy="0.0001" iyz="0" izz="0.0001"/>
    </inertial>
  </link>

  <joint name="joint8" type="revolute">
    <parent link="link8"/>
    <child link="link9"/>
    <origin xyz="0.06 0 0"/>
    <axis xyz="0 0 1"/>
    <limit lower="-1.5" upper="1.5" effort="10" velocity="5"/>
  </joint>

  <link name="link9">
    <visual>
      <geometry>
        <box size="0.06 0.055 0.055"/>
      </geometry>
      <origin xyz="0.03 0 0"/>
      <material name="blue"/>
    </visual>
    <collision>
      <geometry>
        <box size="0.06 0.055 0.055"/>
      </geometry>
      <origin xyz="0.03 0 0"/>
    </collision>
    <inertial>
      <mass value="0.1"/>
      <origin xyz="0.03 0 0"/>
      <inertia ixx="0.0001" ixy="0" ixz="0" iyy="0.0001" iyz="0" izz="0.0001"/>
    </inertial>
  </link>

</robot>

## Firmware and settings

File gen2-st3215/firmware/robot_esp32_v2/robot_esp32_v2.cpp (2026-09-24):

/*
 * SURGE-090 robot firmware — gait + ST3215 bus + MPU6050 + ESP-NOW.
 *
 * Board : Waveshare Servo Driver with ESP32 (servo UART GPIO 18 RX / 19 TX, 1 Mbps)
 * Power : split bus v3 — 3S LiPo -> 15 A fuse -> loop key -> main line, tapped into
 *         5 groups of 2 servos (ID1-2, 3-4, 5-6, 7-8, 9-10), 3 A PTC per tap.
 *         Driver board fed from the main line through a 1N4007 or a buck (<= 12 V).
 *         Driver servo-port +V is cut: the board sends DATA + GND only.
 * IMU   : MPU6050 on SDA 21 / SCL 22 (optional — gait runs without it).
 *
 * What this version adds over the first robot_esp32:
 *   - Boots with torque OFF. Nothing moves until RUN (Serial or base station).
 *   - Soft start: torque is enabled one power group at a time at low speed,
 *     then the wave amplitude ramps in — so the 3 A PTCs do not trip.
 *   - Joint angles clamped to ±70° (mechanical limit of the v6 segment is ±80°).
 *   - Per-joint trim so a straight body really is straight.
 *   - One 15-byte read per servo per cycle (position, voltage, temp, current).
 *   - Stall detection needs several consecutive over-current samples.
 *   - Low-battery (10.2 V) and over-temperature (70 °C) automatic stop.
 *   - ESP-NOW commands are queued and applied in loop() (never on the radio
 *     task), so the servo bus is only ever touched from one place.
 *   - Status parser skips the echo of our own packet if the adapter echoes TX.
 *
 * Serial Monitor 115200, commands (end with Enter):
 *   RUN     start slithering (soft start)
 *   STOP    torque off, horns go limp
 *   CENTER  torque on, hold every joint straight (use while assembling horns)
 *   PING    list which servo IDs answer and their voltage/temperature
 *
 * Telemetry struct and command struct are unchanged — base_esp32 works as is.
 */

#include <Arduino.h>
#include <Wire.h>
#include <WiFi.h>
#include <esp_now.h>
#include <esp_wifi.h>
#include <math.h>
#include "surge_protocol.h"

// ---------------------------------------------------------------- pins / bus
static const int S_RXD = 18;
static const int S_TXD = 19;
static const uint32_t SERVO_BAUD = 1000000;
static const int IMU_SDA = 21;
static const int IMU_SCL = 22;
static const uint8_t IMU_ADDR = 0x68;

// ---------------------------------------------------------------- geometry
static const int NUM_JOINTS = SURGE_NUM_JOINTS;  // 10
static const int ENC_CENTER = 2048;              // 4096 counts = 360°
static const float COUNTS_PER_DEG = 4096.0f / 360.0f;
static const int JOINT_LIMIT = (int)(70.0f * COUNTS_PER_DEG);  // ±70° = ±796

// Straight-body trim per joint (counts). If a joint is not straight at CENTER,
// put the correction here (+ = one way, - = the other). 11 counts ≈ 1°.
static const int16_t TRIM[NUM_JOINTS] = {0, 0, 0, 0, 0, 0, 0, 0, 0, 0};

// ---------------------------------------------------------------- gait
static const float AMPLITUDE_DEG = 30.0f;   // wave amplitude per joint
static const float WAVE_HZ = 0.5f;          // one full wave every 2 s
static const float PHASE_SHIFT = 1.2f;      // rad between neighbouring joints
static const float TURN_DEG = 25.0f;        // extra bend while turning away
static const uint16_t GAIT_SPEED = 2400;    // steps/s cap while slithering
static const uint16_t SOFT_SPEED = 300;     // steps/s while moving to start pose
static const uint8_t GAIT_ACC = 50;
static const uint8_t SOFT_ACC = 20;
static const uint32_t AMP_RAMP_MS = 3000;   // amplitude eases in over 3 s
static const uint32_t GROUP_DELAY_MS = 400; // gap between power groups at start
static const uint16_t TORQUE_LIMIT = 700;   // 0-1000 (x0.1 %) -> 70 % max torque

// ---------------------------------------------------------------- protection
static const int CURRENT_TRIP_MA = 1200;    // stall threshold (calibrate)
static const int STALL_SAMPLES = 4;         // consecutive samples above trip
static const float CURRENT_LSB_MA = 6.5f;
static const uint8_t LOW_BATT_DECIV = 102;  // 10.2 V = 3.4 V/cell
static const uint32_t LOW_BATT_MS = 3000;
static const uint8_t MAX_TEMP_C = 70;
static const float REV_S = 2.5f;
static const float TURN_S = 4.0f;

// ---------------------------------------------------------------- timing
static const uint32_t LOOP_DT_MS = 20;       // 50 Hz control
static const uint32_t TELEMETRY_DT_MS = 100; // 10 Hz radio + serial
static const uint32_t READ_TIMEOUT_MS = 3;

// ---------------------------------------------------------------- ST3215 map
static const uint8_t REG_TORQUE = 40;
static const uint8_t REG_ACC = 41;
static const uint8_t REG_GOAL_POS = 42;      // pos(2) time(2) speed(2)
static const uint8_t REG_TORQUE_LIMIT = 48;  // 2 bytes, RAM
static const uint8_t REG_PRESENT_POS = 56;   // block read 56..70
static const uint8_t BLOCK_LEN = 15;         // 56..70 inclusive
// offsets inside the block
static const int OFF_POS = 0;    // 56-57
static const int OFF_VOLT = 6;   // 62
static const int OFF_TEMP = 7;   // 63
static const int OFF_CUR = 13;   // 69-70
static const uint8_t INST_PING = 0x01;
static const uint8_t INST_READ = 0x02;
static const uint8_t INST_WRITE = 0x03;
static const uint8_t INST_SYNC_WRITE = 0x83;
static const uint8_t BROADCAST_ID = 0xFE;

static uint8_t kBroadcastMac[6] = {0xFF, 0xFF, 0xFF, 0xFF, 0xFF, 0xFF};

// ---------------------------------------------------------------- state
enum Mode : uint8_t { MODE_IDLE, MODE_CENTER, MODE_GAIT };
static Mode g_mode = MODE_IDLE;
static uint8_t g_state = STATE_STOP;   // telemetry state (SurgeState)
static int8_t g_turn = 1;
static uint32_t g_state_end_ms = 0;
static uint32_t g_gait_t0 = 0;
static bool g_imu_ok = false;
static int g_stall_count[NUM_JOINTS] = {0};
static uint32_t g_low_batt_since = 0;

// command handed over from the ESP-NOW callback (radio task) to loop()
static volatile int8_t g_pending_run = -1;   // -1 none, 0 stop, 1 run

// ================================================================ bus layer
static uint8_t scsChecksum(const uint8_t *body, int n) {
  uint16_t s = 0;
  for (int i = 0; i < n; i++) s += body[i];
  return (uint8_t)(~s);
}

static uint8_t g_last_tx[160];
static int g_last_tx_len = 0;

static void busSend(const uint8_t *pkt, int n) {
  while (Serial1.available()) Serial1.read();  // drop stale bytes
  Serial1.write(pkt, n);
  Serial1.flush();
  if (n <= (int)sizeof(g_last_tx)) {
    memcpy(g_last_tx, pkt, n);
    g_last_tx_len = n;
  } else {
    g_last_tx_len = 0;
  }
}

// Build and send one instruction packet: FF FF id len inst params... cs
static void busInstruction(uint8_t id, uint8_t inst, const uint8_t *params, int np) {
  uint8_t pkt[160];
  pkt[0] = 0xFF;
  pkt[1] = 0xFF;
  pkt[2] = id;
  pkt[3] = (uint8_t)(np + 2);
  pkt[4] = inst;
  if (np > 0) memcpy(&pkt[5], params, np);
  pkt[5 + np] = scsChecksum(&pkt[2], np + 3);
  busSend(pkt, np + 6);
}

// Wait for a status packet from `id`. Skips an echo of our own packet.
static bool busReadStatus(uint8_t id, uint8_t *params, int want, uint32_t timeout_ms) {
  uint8_t buf[80];
  int n = 0;
  uint32_t start = millis();
  bool echo_checked = false;
  while (millis() - start < timeout_ms) {
    while (Serial1.available() && n < (int)sizeof(buf)) buf[n++] = (uint8_t)Serial1.read();

    int from = 0;
    if (!echo_checked && g_last_tx_len > 0 && n >= g_last_tx_len) {
      echo_checked = true;
      if (memcmp(buf, g_last_tx, g_last_tx_len) == 0) from = g_last_tx_len;
    }
    for (int i = from; i + 5 < n; i++) {
      if (buf[i] != 0xFF || buf[i + 1] != 0xFF || buf[i + 2] == 0xFF) continue;
      uint8_t sid = buf[i + 2];
      uint8_t len = buf[i + 3];
      int end = i + 3 + len;  // index of checksum
      if (end >= n) break;    // not complete yet
      if (sid != id) continue;
      if (scsChecksum(&buf[i + 2], len + 1) != buf[end]) continue;
      int plen = len - 2;     // minus error byte and checksum
      if (plen < want) continue;
      if (params && want > 0) memcpy(params, &buf[i + 5], want);
      return true;
    }
    delayMicroseconds(50);
  }
  return false;
}

static void writeBytes(uint8_t id, uint8_t addr, const uint8_t *data, int n) {
  uint8_t p[16];
  p[0] = addr;
  memcpy(&p[1], data, n);
  busInstruction(id, INST_WRITE, p, n + 1);
  if (id != BROADCAST_ID) busReadStatus(id, nullptr, 0, READ_TIMEOUT_MS);
}

static void writeByte(uint8_t id, uint8_t addr, uint8_t v) { writeBytes(id, addr, &v, 1); }

static void writeWord(uint8_t id, uint8_t addr, uint16_t v) {
  uint8_t d[2] = {(uint8_t)(v & 0xFF), (uint8_t)(v >> 8)};
  writeBytes(id, addr, d, 2);
}

static bool readBlock(uint8_t id, uint8_t addr, uint8_t len, uint8_t *out) {
  uint8_t p[2] = {addr, len};
  busInstruction(id, INST_READ, p, 2);
  return busReadStatus(id, out, len, READ_TIMEOUT_MS);
}

static bool ping(uint8_t id) {
  busInstruction(id, INST_PING, nullptr, 0);
  return busReadStatus(id, nullptr, 0, READ_TIMEOUT_MS);
}

// One SYNC WRITE sets goal position + speed on all joints at once.
static void syncWriteGoals(const uint16_t *pos, uint16_t speed) {
  uint8_t p[2 + NUM_JOINTS * 7];
  p[0] = REG_GOAL_POS;
  p[1] = 6;
  int o = 2;
  for (int i = 0; i < NUM_JOINTS; i++) {
    p[o++] = (uint8_t)(i + 1);
    p[o++] = (uint8_t)(pos[i] & 0xFF);
    p[o++] = (uint8_t)(pos[i] >> 8);
    p[o++] = 0;
    p[o++] = 0;
    p[o++] = (uint8_t)(speed & 0xFF);
    p[o++] = (uint8_t)(speed >> 8);
  }
  busInstruction(BROADCAST_ID, INST_SYNC_WRITE, p, o);
}

static int16_t signMag(uint16_t raw) {
  int mag = raw & 0x7FFF;
  return (raw & 0x8000) ? (int16_t)(-mag) : (int16_t)mag;
}

// ================================================================ gait
static uint16_t jointTarget(int i, float offset_counts) {
  int off = (int)lroundf(offset_counts);
  if (off > JOINT_LIMIT) off = JOINT_LIMIT;
  if (off < -JOINT_LIMIT) off = -JOINT_LIMIT;
  return (uint16_t)(ENC_CENTER + TRIM[i] + off);
}

static void straightPose(uint16_t *out) {
  for (int i = 0; i < NUM_JOINTS; i++) out[i] = jointTarget(i, 0);
}

// Travelling wave. t in seconds since gait start; ramp 0..1 scales amplitude.
static void gaitPose(float t, float ramp, uint8_t state, int8_t turn, uint16_t *out) {
  const float amp = AMPLITUDE_DEG * COUNTS_PER_DEG * ramp;
  const float dir = (state == STATE_REV) ? -1.0f : 1.0f;
  const float bend = (state == STATE_TURN) ? turn * TURN_DEG * COUNTS_PER_DEG : 0.0f;
  const float w = 2.0f * PI * WAVE_HZ;
  for (int i = 0; i < NUM_JOINTS; i++) {
    float phase = dir * w * t - (i + 1) * PHASE_SHIFT;
    out[i] = jointTarget(i, amp * sinf(phase) + bend);
  }
}

// ================================================================ modes
static void torqueAll(bool on) {
  if (!on) {
    writeByte(BROADCAST_ID, REG_TORQUE, 0);
    return;
  }
  writeByte(BROADCAST_ID, REG_TORQUE, 1);
}

static void enterIdle(const char *why) {
  torqueAll(false);
  g_mode = MODE_IDLE;
  g_state = STATE_STOP;
  Serial.printf("[STOP] %s — torque off\n", why);
}

// Load safe settings, then switch torque on one power group (2 servos) at a
// time while they walk slowly to `pose`. Keeps inrush per 3 A PTC low.
static void softTorqueOn(const uint16_t *pose) {
  writeByte(BROADCAST_ID, REG_ACC, SOFT_ACC);
  writeWord(BROADCAST_ID, REG_TORQUE_LIMIT, TORQUE_LIMIT);
  syncWriteGoals(pose, SOFT_SPEED);
  for (int g = 0; g < NUM_JOINTS / 2; g++) {
    writeByte((uint8_t)(2 * g + 1), REG_TORQUE, 1);
    writeByte((uint8_t)(2 * g + 2), REG_TORQUE, 1);
    delay(GROUP_DELAY_MS);
  }
  delay(1500);  // let every joint arrive at the pose
}

static void enterCenter() {
  uint16_t pose[NUM_JOINTS];
  straightPose(pose);
  Serial.println("[CENTER] holding straight — soft start");
  softTorqueOn(pose);
  g_mode = MODE_CENTER;
  g_state = STATE_STOP;
}

static void enterGait() {
  uint16_t pose[NUM_JOINTS];
  gaitPose(0.0f, 0.0f, STATE_SLITHER, 1, pose);  // amplitude 0 = straight
  Serial.println("[RUN] soft start — keep clear");
  softTorqueOn(pose);
  writeByte(BROADCAST_ID, REG_ACC, GAIT_ACC);
  memset(g_stall_count, 0, sizeof(g_stall_count));
  g_gait_t0 = millis();
  g_state = STATE_SLITHER;
  g_mode = MODE_GAIT;
  Serial.println("[RUN] slithering");
}

static void pingAll() {
  Serial.println("ID  answer  volt  temp");
  int found = 0;
  for (uint8_t id = 1; id <= NUM_JOINTS; id++) {
    uint8_t b[BLOCK_LEN];
    bool ok = ping(id) && readBlock(id, REG_PRESENT_POS, BLOCK_LEN, b);
    if (ok) {
      found++;
      Serial.printf("%2u  yes     %4.1f  %3u C\n", id, b[OFF_VOLT] / 10.0f, b[OFF_TEMP]);
    } else {
      Serial.printf("%2u  NO      ----  ---\n", id);
    }
  }
  Serial.printf("%d/%d servos answered\n", found, NUM_JOINTS);
  if (found == 0) Serial.println("None answered: check GND link, 18/19 pins, and servo power.");
}

// ================================================================ IMU
static bool imuBegin() {
  Wire.begin(IMU_SDA, IMU_SCL);
  Wire.setClock(400000);
  Wire.beginTransmission(IMU_ADDR);
  Wire.write(0x6B);
  Wire.write(0x00);
  return Wire.endTransmission() == 0;
}

static void imuRead(int16_t acc_mg[3], int16_t gyro_dps_x10[3]) {
  for (int k = 0; k < 3; k++) acc_mg[k] = gyro_dps_x10[k] = 0;
  if (!g_imu_ok) return;
  Wire.beginTransmission(IMU_ADDR);
  Wire.write(0x3B);
  if (Wire.endTransmission(false) != 0) return;
  if (Wire.requestFrom((int)IMU_ADDR, 14) < 14) return;
  int16_t r[7];
  for (int k = 0; k < 7; k++) {
    uint8_t hi = (uint8_t)Wire.read();  // two statements: C++ does not fix
    uint8_t lo = (uint8_t)Wire.read();  // the order of reads in one expression
    r[k] = (int16_t)((hi << 8) | lo);
  }
  for (int k = 0; k < 3; k++) {
    acc_mg[k] = (int16_t)((int32_t)r[k] * 1000 / 16384);          // ±2 g
    gyro_dps_x10[k] = (int16_t)((int32_t)r[k + 4] * 10 / 131);    // ±250 dps
  }
}

// ================================================================ radio
#if defined(ESP_ARDUINO_VERSION_MAJOR) && ESP_ARDUINO_VERSION_MAJOR >= 3
void onRecv(const esp_now_recv_info_t *info, const uint8_t *data, int len) {
  (void)info;
#else
void onRecv(const uint8_t *mac, const uint8_t *data, int len) {
  (void)mac;
#endif
  if (len == (int)sizeof(RobotCommand)) {
    RobotCommand cmd;
    memcpy(&cmd, data, sizeof(cmd));
    g_pending_run = cmd.run ? 1 : 0;  // applied in loop(), never here
  }
}

static void setupEspNow() {
  WiFi.mode(WIFI_STA);
  WiFi.disconnect();
  if (esp_now_init() != ESP_OK) {
    Serial.println("ESP-NOW init failed — Serial control only");
    return;
  }
  esp_now_register_recv_cb(onRecv);
  esp_now_peer_info_t peer = {};
  memcpy(peer.peer_addr, kBroadcastMac, 6);
  peer.channel = 0;
  peer.encrypt = false;
  if (esp_now_add_peer(&peer) != ESP_OK) Serial.println("ESP-NOW add peer failed");
}

// ================================================================ commands
static void handleSerial() {
  if (!Serial.available()) return;
  String s = Serial.readStringUntil('\n');
  s.trim();
  s.toUpperCase();
  if (s == "RUN") g_pending_run = 1;
  else if (s == "STOP") g_pending_run = 0;
  else if (s == "CENTER") { if (g_mode == MODE_IDLE) enterCenter(); else Serial.println("STOP first"); }
  else if (s == "PING") { if (g_mode == MODE_IDLE) pingAll(); else Serial.println("STOP first"); }
  else if (s.length()) Serial.println("Commands: RUN  STOP  CENTER  PING");
}

static void applyPending() {
  int8_t p = g_pending_run;
  if (p < 0) return;
  g_pending_run = -1;
  if (p == 0) {
    if (g_mode != MODE_IDLE) enterIdle("command");
  } else if (g_mode != MODE_GAIT) {
    enterGait();
  }
}

// ================================================================ setup / loop
void setup() {
  Serial.begin(115200);
  Serial.setTimeout(50);
  Serial1.begin(SERVO_BAUD, SERIAL_8N1, S_RXD, S_TXD);
  delay(500);

  Serial.println("\nSURGE-090 robot ESP32 — ST3215 x10, split power bus v3");
  torqueAll(false);  // whatever state the servos were left in: go limp
  g_imu_ok = imuBegin();
  Serial.println(g_imu_ok ? "MPU6050 ok" : "MPU6050 missing — gait still works");
  setupEspNow();
  Serial.printf("STA MAC %s\n", WiFi.macAddress().c_str());
  pingAll();
  Serial.println("Idle, torque OFF. Type RUN, STOP, CENTER or PING.");
}

void loop() {
  const uint32_t now = millis();
  static uint32_t last_tel = 0;

  handleSerial();
  applyPending();

  // ---- read every servo once (position, voltage, temperature, current)
  int16_t cur[NUM_JOINTS] = {0};
  uint16_t pos[NUM_JOINTS] = {0};
  uint8_t vmin = 0, tmax = 0;
  int answered = 0;
  for (uint8_t id = 1; id <= NUM_JOINTS; id++) {
    uint8_t b[BLOCK_LEN];
    if (!readBlock(id, REG_PRESENT_POS, BLOCK_LEN, b)) continue;
    answered++;
    pos[id - 1] = (uint16_t)(b[OFF_POS] | (b[OFF_POS + 1] << 8));
    cur[id - 1] = (int16_t)(signMag((uint16_t)(b[OFF_CUR] | (b[OFF_CUR + 1] << 8))) * CURRENT_LSB_MA);
    uint8_t v = b[OFF_VOLT];
    if (vmin == 0 || v < vmin) vmin = v;
    if (b[OFF_TEMP] > tmax) tmax = b[OFF_TEMP];
  }

  // ---- protection (active whenever torque is on)
  if (g_mode != MODE_IDLE) {
    if (answered > 0 && vmin < LOW_BATT_DECIV) {
      if (g_low_batt_since == 0) g_low_batt_since = now;
      if (now - g_low_batt_since > LOW_BATT_MS) enterIdle("low battery (<10.2 V) — charge the pack");
    } else {
      g_low_batt_since = 0;
    }
    if (g_mode != MODE_IDLE && tmax >= MAX_TEMP_C) enterIdle("servo over 70 C — let it cool");
  }

  // ---- gait
  if (g_mode == MODE_GAIT) {
    if (g_state == STATE_REV || g_state == STATE_TURN) {
      if ((int32_t)(now - g_state_end_ms) >= 0) {
        if (g_state == STATE_REV) {
          g_state = STATE_TURN;
          g_state_end_ms = now + (uint32_t)(TURN_S * 1000);
          Serial.println("[EVADE] reverse -> turn");
        } else {
          g_state = STATE_SLITHER;
          memset(g_stall_count, 0, sizeof(g_stall_count));
          Serial.println("[EVADE] resume slither");
        }
      }
    } else {
      for (int i = 0; i < NUM_JOINTS; i++) {
        g_stall_count[i] = (abs(cur[i]) > CURRENT_TRIP_MA) ? g_stall_count[i] + 1 : 0;
        if (g_stall_count[i] >= STALL_SAMPLES) {
          g_turn = cur[i] > 0 ? -1 : 1;
          g_state = STATE_REV;
          g_state_end_ms = now + (uint32_t)(REV_S * 1000);
          Serial.printf("[ALERT] servo %d stalled at %d mA -> reverse\n", i + 1, cur[i]);
          break;
        }
      }
    }
    const uint32_t dt = now - g_gait_t0;
    const float ramp = dt < AMP_RAMP_MS ? (float)dt / AMP_RAMP_MS : 1.0f;
    uint16_t goals[NUM_JOINTS];
    gaitPose(dt / 1000.0f, ramp, g_state, g_turn, goals);
    syncWriteGoals(goals, GAIT_SPEED);
  }

  // ---- telemetry at 10 Hz
  if (now - last_tel >= TELEMETRY_DT_MS) {
    last_tel = now;
    int16_t acc[3], gyro[3];
    imuRead(acc, gyro);
    RobotTelemetry tel = {};
    tel.t_ms = now;
    tel.state = g_state;
    tel.turn_dir = g_turn;
    memcpy(tel.current_ma, cur, sizeof(cur));
    memcpy(tel.position, pos, sizeof(pos));
    memcpy(tel.acc_mg, acc, sizeof(acc));
    memcpy(tel.gyro_dps_x10, gyro, sizeof(gyro));
    tel.vin_deciV = vmin;
    esp_now_send(kBroadcastMac, (uint8_t *)&tel, sizeof(tel));

    int total = 0;
    for (int i = 0; i < NUM_JOINTS; i++) total += abs(cur[i]);
    Serial.printf("T,%lu,state=%u,servos=%d/%d,V=%.1f,Tmax=%u,Itot=%dmA\n",
                  (unsigned long)now, (unsigned)g_state, answered, NUM_JOINTS,
                  vmin / 10.0f, (unsigned)tmax, total);
  }

  const uint32_t elapsed = millis() - now;
  if (elapsed < LOOP_DT_MS) delay(LOOP_DT_MS - elapsed);
}

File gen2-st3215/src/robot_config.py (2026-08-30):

import math
import os
import sys


class St3215Addr:
    """
    EEPROM / SRAM control table for Waveshare ST3215 (Feetech SMS/STS).

    Addresses are byte offsets. Multi-byte fields are little-endian.
    VIN on the Waveshare driver is passed straight to this bus — keep it
    inside 6.0–12.6 V (3S LiPo charged = 12.6 V max).
    """

    ID = 5  # 1 byte  EEPROM
    BAUD_RATE = 6  # 1 byte  EEPROM
    MIN_ANGLE_LIMIT = 9  # 2 bytes EEPROM
    MAX_ANGLE_LIMIT = 11  # 2 bytes EEPROM
    TORQUE_ENABLE = 40  # 1 byte  SRAM  0=off, 1=on
    ACC = 41  # 1 byte  SRAM
    GOAL_POSITION = 42  # 2 bytes SRAM
    GOAL_TIME = 44  # 2 bytes SRAM
    GOAL_SPEED = 46  # 2 bytes SRAM
    LOCK = 55  # 1 byte  EEPROM  0=unlock, 1=lock
    PRESENT_POSITION = 56  # 2 bytes SRAM
    PRESENT_SPEED = 58  # 2 bytes SRAM
    PRESENT_LOAD = 60  # 2 bytes SRAM
    PRESENT_VOLTAGE = 62  # 1 byte  SRAM  unit 0.1 V
    PRESENT_TEMPERATURE = 63  # 1 byte  SRAM  °C
    MOVING = 66  # 1 byte  SRAM
    PRESENT_CURRENT = 69  # 2 bytes SRAM  bit15=sign, unit 6.5 mA


class Config:
    # ---------------------------
    # Physical robot
    # ---------------------------
    NUM_JOINTS = 10
    LINK_LENGTH_M = 0.058  # v6 segment pitch (58 mm)
    MODULE_MASS_KG = 0.25

    # Planar ST3215 chain: every joint is yaw (shaft along Z).
    # Gen-1 alternating pitch/yaw is not used on this body.
    PLANAR_ALL_YAW = True

    # ---------------------------
    # ST3215 limits
    # ---------------------------
    MAX_TORQUE_NM = 2.94  # 30 kg·cm @ 12 V
    MAX_ANGLE_RAD = math.pi / 2
    STALL_CURRENT_MA = 2700
    NO_LOAD_CURRENT_MA = 200
    CURRENT_UNIT_MA = 6.5  # Feetech present-current LSB
    VIN_MIN_V = 6.0
    VIN_MAX_V = 12.6

    ENCODER_MIN = 0
    ENCODER_MAX = 4095
    ENCODER_CENTER = 2048  # 12-bit magnetic encoder, same span as XL330

    # ---------------------------
    # Servo bus (Waveshare driver ESP32 UART1)
    # ---------------------------
    BAUDRATE = 1_000_000
    PROTOCOL = "feetech-sts"
    BROADCAST_ID = 0xFE
    SERVO_RX_GPIO = 18  # Waveshare Servo Driver with ESP32 default
    SERVO_TX_GPIO = 19

    # ---------------------------
    # Gait (was buried in SnakeKinematics instance attrs)
    # ---------------------------
    GAIT_AMPLITUDE = 400  # encoder ticks (~35°)
    GAIT_FREQUENCY = 3.0  # rad/s of the travelling wave
    GAIT_PHASE_SHIFT = 1.2  # rad per joint index
    GAIT_TURN_OFFSET = 300  # ticks of uniform yaw bias while turning
    GOAL_SPEED = 2400  # STS speed units; caps slam on first move
    GOAL_ACC = 50

    # ---------------------------
    # Bellows model (optional; not the live gait)
    # ---------------------------
    K_0 = 0.5
    K_S = 1.0
    K_T = 2.0
    PSI_D = 0.0
    PSI_L = math.pi / 2

    # ---------------------------
    # Control loop
    # ---------------------------
    CONTROL_HZ = 50
    DT = 1.0 / CONTROL_HZ

    P_POS = 2.5
    D_POS = 0.1
    P_VEL = 0.5

    MU_MAX = 1.0
    MU_MIN = 0.1
    POS_ERROR_THRESHOLD = 0.3
    K_RADIUS = 0.5

    # ---------------------------
    # Obstacle avoidance (current / load)
    # Calibrate on the bench: free-run ~200 mA, stall 2.7 A.
    # 1200 mA is a starting trip, not a measured value.
    # ---------------------------
    OBSTACLE_CURRENT_THRESHOLD_MA = 1200
    EVASION_REVERSE_DURATION_S = 2.5
    EVASION_TURN_DURATION_S = 4.0

    # ---------------------------
    # MPU6050 on robot ESP32
    # ---------------------------
    IMU_I2C_ADDR = 0x68
    IMU_SDA_GPIO = 21
    IMU_SCL_GPIO = 22

    # ---------------------------
    # ESP-NOW
    # ---------------------------
    ESPNOW_CHANNEL = 1
    USB_TELEMETRY_BAUD = 115200


def default_serial_port() -> str:
    """USB CDC of the Waveshare driver (bench) or a USB-TTL adapter."""
    env = os.environ.get("SURGE_PORT")
    if env:
        return env
    if sys.platform.startswith("win"):
        return "COM3"
    for candidate in ("/dev/ttyUSB0", "/dev/ttyACM0"):
        if os.path.exists(candidate):
            return candidate
    return "/dev/ttyUSB0"

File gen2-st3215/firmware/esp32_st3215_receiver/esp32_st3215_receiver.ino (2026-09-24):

#include "soc/rtc_cntl_reg.h"
#include "soc/soc.h"
#include <Adafruit_GFX.h>
#include <Adafruit_SSD1306.h>
#include <Adafruit_NeoPixel.h>
#include <math.h>
#include <SCServo.h>
#include <WiFi.h>
#include <Wire.h>
#include <esp_mac.h>
#include <esp_now.h>
#include <esp_wifi.h>

volatile char wirelessBuffer[250];
volatile bool hasWirelessCmd = false;
enum ConnectionState {
  STATE_INIT,
  STATE_DISCONNECTED,
  STATE_USB,
  STATE_ESPNOW,
  STATE_BOTH
};
ConnectionState currentState = STATE_INIT;
unsigned long lastUsbTime = 0;
unsigned long lastEspNowTime = 0;
unsigned long holdMessageUntil = 0;
void OnDataRecv(const esp_now_recv_info *info, const uint8_t *incomingData,
                int len) {
  if (len < 250) {
    memcpy((void *)wirelessBuffer, incomingData, len);
    wirelessBuffer[len] = '\0';
    hasWirelessCmd = true;
  }
}
#define SCREEN_WIDTH 128
#define SCREEN_HEIGHT 32
#define OLED_RESET -1
Adafruit_SSD1306 display(SCREEN_WIDTH, SCREEN_HEIGHT, &Wire, OLED_RESET);

#define LED_PIN 23
#define LED_COUNT 2
Adafruit_NeoPixel strip(LED_COUNT, LED_PIN, NEO_GRB + NEO_KHZ800);

int globalMaxLoad = 0;
unsigned long lastTelemetryTime = 0;
bool telemetryActive = false;
void updateDisplay(ConnectionState newState) {
  if (currentState == newState)
    return;
  if (millis() < holdMessageUntil && newState == STATE_DISCONNECTED)
    return;
  currentState = newState;
  display.clearDisplay();
  display.setTextSize(1);
  display.setTextColor(SSD1306_WHITE);
  display.setCursor(0, 0);
  display.println("Snake SURGE");
  if (newState == STATE_DISCONNECTED) {
    display.println("Status: Waiting...");
    uint8_t mac[6];
    esp_read_mac(mac, ESP_MAC_WIFI_STA);
    char macStr[18];
    snprintf(macStr, sizeof(macStr), "%02X:%02X:%02X:%02X:%02X:%02X", mac[0],
             mac[1], mac[2], mac[3], mac[4], mac[5]);
    display.println(macStr);
  } else if (newState == STATE_USB) {
    display.println("Status: USB Active");
  } else if (newState == STATE_ESPNOW) {
    display.println("Status: Wireless RX");
  } else if (newState == STATE_BOTH) {
    display.println("Status: USB+Wireless");
  }
  display.display();
}

void updateLEDs() {
  unsigned long now = millis();
  
  // LED 0: Connection Status
  if (currentState == STATE_DISCONNECTED) {
    // Smooth breathing animation (White)
    uint8_t breath = (sin(now / 400.0) + 1.0) * 40.0; 
    strip.setPixelColor(0, strip.Color(breath, breath, breath));
  } else if (currentState == STATE_USB) {
    strip.setPixelColor(0, strip.Color(0, 0, 255)); // Blue
  } else if (currentState == STATE_ESPNOW) {
    strip.setPixelColor(0, strip.Color(0, 255, 0)); // Green
  } else if (currentState == STATE_BOTH) {
    strip.setPixelColor(0, strip.Color(0, 255, 255)); // Cyan
  }

  // LED 1: Telemetry & Error Status
  if (now - lastTelemetryTime > 2000) {
    telemetryActive = false;
  }
  
  if (!telemetryActive) {
    strip.setPixelColor(1, 0); // Off if no telemetry running
  } else if (globalMaxLoad == -1) {
    strip.setPixelColor(1, strip.Color(255, 0, 0)); // Hardware Error (No response)
  } else if (globalMaxLoad > 600) {
    // Flashing Red Warning for Overload (>60%)
    if ((now / 150) % 2 == 0) {
      strip.setPixelColor(1, strip.Color(255, 0, 0));
    } else {
      strip.setPixelColor(1, 0);
    }
  } else if (globalMaxLoad > 300) {
    // Solid Yellow (Moderate Load)
    strip.setPixelColor(1, strip.Color(255, 120, 0));
  } else {
    // Solid Green (Normal Safe Load)
    strip.setPixelColor(1, strip.Color(0, 255, 0));
  }
  
  strip.show();
}
SMS_STS st;
#define S_RXD 18
#define S_TXD 19
void setup() {
  WRITE_PERI_REG(RTC_CNTL_BROWN_OUT_REG, 0);
  Serial.begin(115200);
  Serial1.begin(1000000, SERIAL_8N1, S_RXD, S_TXD);
  st.pSerial = &Serial1;
  Wire.begin(21, 22);
  display.begin(SSD1306_SWITCHCAPVCC, 0x3C);

  strip.begin();
  strip.show(); // Initialize all pixels to 'off'
  strip.setBrightness(50); // Set brightness to 20% (max is 255)

  WiFi.mode(WIFI_STA);
  WiFi.disconnect();
  esp_wifi_set_channel(1, WIFI_SECOND_CHAN_NONE);
  updateDisplay(STATE_DISCONNECTED);
  if (esp_now_init() == ESP_OK) {
    esp_now_register_recv_cb(OnDataRecv);
    uint8_t bcast[] = {0xFF, 0xFF, 0xFF, 0xFF, 0xFF, 0xFF};
    esp_now_peer_info_t peer;
    memset(&peer, 0, sizeof(peer));
    memcpy(peer.peer_addr, bcast, 6);
    peer.channel = 1;
    peer.encrypt = false;
    peer.ifidx = WIFI_IF_STA;
    esp_now_add_peer(&peer);
  }
}
void processCommand(String req) {
  req.trim();
  if (req.startsWith("P,")) {
    String data = req.substring(2);
    int startIdx = 0;
    while (startIdx < data.length()) {
      int commaIdx = data.indexOf(',', startIdx);
      if (commaIdx == -1)
        commaIdx = data.length();
      String pair = data.substring(startIdx, commaIdx);
      int colonIdx = pair.indexOf(':');
      if (colonIdx != -1) {
        int id = pair.substring(0, colonIdx).toInt();
        int pos = pair.substring(colonIdx + 1).toInt();
        st.WritePosEx(id, pos, 3400, 50);
      }
      startIdx = commaIdx + 1;
    }
  } else if (req.startsWith("I,")) {
    int newId = req.substring(2).toInt();
    st.unLockEprom(254);
    st.writeByte(254, 5, newId);
    st.LockEprom(254);
    display.clearDisplay();
    display.setCursor(0, 0);
    display.println("SUCCESS!");
    display.println("Servo ID is now: " + String(newId));
    display.display();
    holdMessageUntil = millis() + 3000;
    currentState = STATE_INIT;
    Serial.println("ID_SET_OK");
  } else if (req == "T") {
    String response = "T,";
    int currentMaxLoad = -1;
    int respondedCount = 0;
    
    for (int i = 1; i <= 10; i++) {
      if (st.FeedBack(i) != -1) {
        respondedCount++;
        int pos = st.ReadPos(-1);
        int vel = st.ReadSpeed(-1);
        int load = st.ReadLoad(-1);
        if (load > currentMaxLoad) currentMaxLoad = load;
        
        response += String(i) + ":" + String(load) + ":" + String(vel) + ":" +
                    String(pos) + ",";
      }
    }
    
    if (respondedCount == 0) {
      globalMaxLoad = -1; // Comms completely dead
    } else {
      globalMaxLoad = currentMaxLoad;
    }
    lastTelemetryTime = millis();
    telemetryActive = true;
    Serial.println(response);
    uint8_t bcast[] = {0xFF, 0xFF, 0xFF, 0xFF, 0xFF, 0xFF};
    esp_now_send(bcast, (uint8_t *)response.c_str(), response.length());
  }
}
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

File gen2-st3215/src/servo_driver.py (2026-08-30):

"""Hardware abstraction for Waveshare ST3215 on a Feetech 1 Mbps bus."""

from __future__ import annotations

import random
import time

from .feetech_protocol import FeetechBus
from .robot_config import Config, St3215Addr, default_serial_port
from .utils import encoder_to_radians, to_signed_current


class ServoState:
    def __init__(self, joint_id: int):
        self.joint_id = joint_id
        self.position = 0.0  # radians
        self.velocity = 0.0  # rad/s
        self.load = 0.0  # Nm proxy
        self.current_ma = 0
        self.encoder = Config.ENCODER_CENTER
        self.voltage_v = 0.0
        self.temperature_c = 0


class ServoDriver:
    """
    ST3215 bus driver.

    Real hardware: USB CDC of the Waveshare board flashed with
    ``firmware/usb_servo_bridge``, or any USB-TTL adapter on the 3-pin bus.
    Field robot: the ESP32 sketch owns Serial1; this class is for bench/PC.

    Set ``mock=True`` (or env SURGE_MOCK=1) to run without servos.
    """

    def __init__(
        self,
        num_servos: int = Config.NUM_JOINTS,
        port: str | None = None,
        baudrate: int = Config.BAUDRATE,
        mock: bool = False,
    ):
        self.num_servos = num_servos
        self.port = port or default_serial_port()
        self.baudrate = baudrate
        self.mock = mock
        self.states = [ServoState(i + 1) for i in range(num_servos)]
        self._target_torques = [0.0] * num_servos
        self._bus: FeetechBus | None = None
        self._ser = None

    def connect(self) -> bool:
        if self.mock:
            print("[ServoDriver] Mock ST3215 bus (no serial).")
            return True
        try:
            import serial
        except ImportError as exc:
            raise ImportError("pyserial is required: pip install pyserial") from exc
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

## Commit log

2026-08-30 docs: add project README and hardware inventory
    SURGE-090 master README covering abstract, two-generation history,
    system architecture, repository layout, and known issues.
    Hardware inventory with resolved power architecture, firmware status,
    9 in-hand components, and 17 missing items with cost estimates.
2026-08-30 feat(gen1): add Dynamixel XL330 snake robot -- code, CAD, and docs
    Generation 1 design targeting Dynamixel XL330-M288-T servos (HISTORICAL).
    Hardware no longer held -- XL330 unobtainable in India, project pivoted
    to ST3215. Includes:
    - Python gait engine (serpenoid kinematics, 50 Hz control loop)
    - Sensorless collision detection via motor current feedback
    - Evasion FSM (reverse, turn, resume)
    - SolidWorks body segment CAD (v1/v2 with STL + STEP exports)
    - Updated hardware BOM marked as historical with carry-forward table
    - BOM.xlsx with Gen 1 (historical) + Gen 2 (current) sheets
    - Wiring diagrams, parts and safety doc, Pi setup guide
    - Test scripts for ping and motor feedback verification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
    [BOM.xlsx, XL,XC-330.SLDASM, XL,XC-330.stp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]
2026-08-30 feat(gen2): add ST3215 snake robot -- code, firmware, CAD, and docs
    Generation 2 redesign for Waveshare/Feetech ST3215 servos on the
    Waveshare Bus Servo Driver with integrated ESP32. Includes:
    - Feetech protocol driver (1 Mbps, sign-magnitude current decoding)
    - 10-DOF planar gait with current-stall collision detection (1200 mA)
    - ESP32 firmware: USB servo bridge, robot CPG+IMU node, base station
    - Arduino servo ID assignment sketch
    - CadQuery parametric body segment (v6 STEP + STL)
    - Wiring diagram (SVG), additional parts spreadsheet
    - LaTeX progress reports (electrical system)
    - Base station script for ESP-NOW telemetry reception
    - Mock-bus mode (SURGE_MOCK=1) for development without hardw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
    [ST3215.dxf, ST3215.step, snake_segment.3mf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]
2026-08-30 feat(sim): add Wokwi ESP32 ultrasonic sensor simulation
    ESP32 DevKit + HC-SR04 simulation for the head-mounted distance
    sensor node. Includes diagram.json, sketch.ino, libraries.txt,
    and screenshot. Recording video removed to keep repo lightweight.
2026-08-30 docs: update all README files with current hardware state
    - Root README: fix power specs (1x 3S 1800mAh, not 2x 1500mAh parallel),
    correct Waveshare driver name (integrated ESP32, not Adapter A),
    update runtime estimates and power architecture diagram
    - Gen 1 README: add HISTORICAL banner, update hardware table with
    obtained/returned status and actual spend (22,400 of 1,00,000)
    - Gen 2 README: add assembly/ folder to repo layout
    - Wokwi README: expand from basic sensor-only description to full
    5-servo snake simulation with gait engine and serial console docs
2026-09-03 Organize gen2-st3215 cad folder and update firmware/docs
    [Assem3.SLDASM, GE_27_1.step.SLDPRT, GE_27_2.step.SLDPRT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]
2026-09-24 Sync Gen 2 docs with split power bus v3 and robot_esp32_v2
    - Firmware README / PORTING_STATUS: robot_esp32_v2 is the field firmware of
    record (limp boot, per-group soft start, ±70° limits, 10.2 V / 70 °C stop);
    robot_esp32 marked superseded.
    - Main README: status table, power figures, architecture and quick start
    updated for split bus v3; hardware inventory link fixed.
    - docs/: wiring, parts & safety, additional parts and app manual rewritten for
    Gen 2; each keeps a "What changed" table and the previous version.
    - docs/hardware/: inventory moved here and updated; superseded power designs
    (centre-fed v1, split bus v2, first Gen 2 concept) added with a history index.
    - Removed dri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
    [snake.urdf]
2026-10-15 Rewrite project READMEs around current research and development history
2026-10-22 Update Gen2 firmware/drivers, Gen3 3D locomotion, test suite, and docs
2026-10-25 web dashboard update and re-calibration
2026-10-30 feat(web): complete 3D snake generation transition, simulation UX, and security hardening
    - Complete 3D robotic-snake loading transition between Gen 2.1 and Gen 3 with GSAP timeline, Three.js 11-link/10-joint model, and Playdate/Slush visual styling.
    - Add readiness gate hold at 2.4s, reduced-motion bypass, SVG fallback, and 10s recovery handling.
    - Harden 3d_viewer.html against missing WebGL environments and fix malformed SVG in index.html.
    - Add browser Playwright test suite in test_generation_transition_browser.py (16/16 passing).
    - Harden simulation UX with full path traversal, cross-track PID steering, parameter descriptions, and run snapshots.
    - Apply CodeRabbit security remediations (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
2026-11-03 mobile controller, new battery, battery percentage correction

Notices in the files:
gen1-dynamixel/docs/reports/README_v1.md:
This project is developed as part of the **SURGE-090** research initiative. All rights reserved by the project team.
